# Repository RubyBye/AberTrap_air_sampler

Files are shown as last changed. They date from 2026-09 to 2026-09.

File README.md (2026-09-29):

# AberTrap air sampler

Open-source design for a novel, lightweight, programmable sampler of airborne biological particles. Compatible with eDNA metabarcoding.

This repository contains all the necessary files, instructions, and documentation for constructing and using the AberTrap.  It accompanies [this publication](https://www.biorxiv.org/content/10.64898/2026.09.02.746715v1)

## Device Features

- Portable and lightweight

- Low cost

- Allows for replicated air sampling in hard to reach locations.

- Open-source and programmable for easy modification and development.

## Repository Contents

- Components
    - Details of the components needed for building, programming and deploying your own AberTrap, with example products and suppliers.

- Assembly
    - Documentation on device assembly, including files for 3D printer and laser cutter

- Programming
    - Documentation on programming the microcontroller, including the Arduino sketch files.

- Validation and testing
    - Documentation on how to check that your AberTrap is working as expected

## Getting Started
1. Read the [Publication](https://www.biorxiv.org/content/10.64898/2026.09.02.746715v1)
2. Gather the required materials and equipment as specified in [Components](./Components/).
3. Follow the [Assembly Instructions](./Assembly/AberTrap_Assembly_instructions.md) to build the device.
4. Follow the [Programming Instructions](./Programming/Trinket_programming_instructions.md) to set it spinning.
5. Perform a [Test Run](./Validation_and_testing) to check that it is working as expected.
6. Deploy!

## How to Contribute
We welcome contributions! Please submit a pull request or open an issue if you have suggestions or improvements. For questions or feedback, contact [rub13@aber.ac.uk](mailto:rub13@aber.ac.uk).

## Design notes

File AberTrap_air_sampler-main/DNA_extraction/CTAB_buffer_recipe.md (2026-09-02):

# CTAB buffer recipe

## Ingredients
CTAB DNA extraction buffer contains:
- 100 mM Tris-HCl (pH 8.0)
- 1.4 M NaCl
- 20 mM EDTA
- 2% hexadecyltrimethylammonium bromide (CTAB).

How much to make: Each extraction uses 1ml of CTAB buffer 

## Sterilisation
- sterilise by autoclaving 15 minutes at 121 degrees celsius

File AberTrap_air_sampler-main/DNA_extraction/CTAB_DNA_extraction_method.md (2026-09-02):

# DNA extraction from AberTrap paddles
CTAB method 

## Before starting
Make fresh 70% ethanol. Store in icebox.  

Set heat block to 60 ℃ 

## Method  
- Remove aerosol loaded paddles (stored in 2 ml screwcap microcentrifuge tube) from freezer
   
**In sterile flow cabinet:**

- Add 200 ul of sterile 200 um glass beads to each tube.
- Add 1ml [CTAB buffer](CTAB_buffer_recipe.md). 
- Beat 2 min using Disruptor Genie.
- Transfer tubes to heat block (60 ℃ x 60 min). Vortex 3x during incubation.
- Spin (13,000 rpm x 1 min) to draw down beads. Remove and discard paddles using sterile forceps.
   
**In fume hood:**

- Add 500ul Phenol/chloroform. Vortex until emulsion forms (~ 5 sec). Spin (13,000 rpm x 2 min) to separate phases. 
- Transfer the upper aqueous phase (900 ul, containing the DNA) into a new 2 ml tube.
- Add 500 ul chloroform/isoamyl alcohol (24:1 v/v). Vortex 5 sec. Spin (13,000 rpm x 2 min) to separate phases. 
- Transfer the upper aqueous phase (800 ul, containing the DNA) to a new 1.5 ml tube (this is the final tube so label fully). 
      
**In sterile flow cabinet:** 

- Add 0.7x volume (~560 ul) RT isopropanol to precipitate DNA, with 1.5 ul glycol blue. Vortex briefly. Leave at RT x 5 min. 
- Spin (13,000 rpm x 10 min) to pellet the DNA.
- Pour off the supernatant, taking care to retain the DNA pellet (which will be blue from glyco-blue). 
- Wash:
   - add fresh, cold 70% ethanol (500 ul).
   - Vortex briefly.
   - Pulse spin to re-attach the pellet.
   - Carefully pour off the ethanol, retaining the pellet.
  
- Repeat wash once more.
- Upturn the tube onto a sterile tissue to drain.
- To evaporate residual ethanol, leave with lid open on heat block for 10 min.
- Re-dissolve DNA in [TE buffer](TE_buffer_recipe.md) (100 µl).

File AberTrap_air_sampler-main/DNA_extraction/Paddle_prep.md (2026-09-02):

# Prepare paddles for aerosol capture

## Wash paddles
To remove any grease/contamination aquired during cutting  of perspex sheet

**In sterile PCR cabinet**
1. Detach the paddles from the perspex sheet (making sure to remove both the central pieces from the slots) and drop into a bowl of soapy water
2. Rub gently (with sterile gloves) then rinse in a bowl of sterile water
3. Lay out to dry overnight on paper towels
4. Next day once dry, before greasing, zap with the hood's UV for 15 mins

## Coat with grease
**In sterile flow hood with external extraction**
1. Prepare Vaseline - hexane suspension (50 mg/ml) in a small sterile glass vessel eg 10 ml flask.

*note* Reserve a pot of Vaseline exclusively for this purpose and only open in sterile flow hood.
*note* The hood must be externally venting to safely remove the Hexane fumes during drying. 

2. Mix for approx 15 mins to allow the Vaseline to fully suspend.
3. Using a pair of sterile forceps, dip each paddle into the Vaseline - Hexane suspension. 
4. Place onto a wire rack (still under a sterile flow) to allow evaporation of the Hexane (5 mins), leaving a thin film of Vaseline covering the entire paddle surface.

## Package
1. Fit each greased paddle into the slot on an AberTrap arm. Use a pair of sterile forceps through the donut slots to manipulate.

*note* The curved upper corner of the paddle should face outward of when fitted into the arm. During operation, the direction of AberTrap rotation is clockwise, therefore by fitting the paddle in a known orientation the capture face can be easily determined.

2. Push a 2 ml screwcap centrifuge tube (without lid) over each paddle, where it securely locks into position on the arm. This shroud prevents contamination of the paddle prior to sampling, which is of utmost importance when conducting eDNA analyses.
3. Package the loaded arms into a box ready for transport to the experimental location. Do not remove the shroud from the tube until the arm is fitted to an AberTrap and experiment starts.

*long term storage* if paddles are not to be used immediately, seal into sterile 2ml tube and store double bagged. When needed, fit into arms under sterile conditions as above.

## Control 
To verify that paddles were successfully kept free of contamination, retain both:
- a greased paddle prior to loading onto the arms. Store in one of the sterile 2 ml microcentrifuge tubes used as shrouds.
- a pair of paddles fitted to the AberTrap and covered with shroud. Bring these to the sample site, but return to the lab unopened.

Process these negative controls alongside experimental samples. They should be completely free of DNA.

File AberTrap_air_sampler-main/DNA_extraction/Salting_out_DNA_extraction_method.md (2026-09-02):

# DNA extraction from AberTrap paddles
Salting out method 

## Before starting
Make fresh 70% ethanol. Store in icebox  
Set heat block to 60 ℃ 
Work entirely in PCR cabinet, except for bead beating and incubation steps

## Method  
- Remove aerosol loaded paddles (stored in 2 ml screwcap microcentrifuge tube) from freezer
   
### Macerate tissue
- Add 200 ul of sterile glass disruption beads * to each tube.
- Add salt lysis buffer (515 ul). 
- Beat 5 min using Disruptor Genie.

### Lyse cells
- Add SDS (57 ul = 2% final conc). Vortex briefly to mix. Pulse spin to get everything to bottom of tube
- Transfer tubes to heat block (60 ℃ x 60 min). Vortex every 15 mins incubation.
- Pulse spin (13,000 rpm) to draw down beads. Remove and discard paddles using sterile forceps.
   
### Precipitate proteins
- Add saturated NaCl (400 ul, 0.7x volumes). Vortex. The proteins will precipitate, the DNA remains in solution. 
- Spin down (13,000 rpm x 5 min) to pellet the proteins.
- Transfer supernatant (800 ul, containing the DNA) to a new 1.5ml tube.
- Repeat spindown
- Transfer the supernatant (750 ul) to a new 1.5 ml tube (this is the final tube so label fully)

### Precipitate DNA
- Add room temp isopropanol (~525 ul, 0.7x volumes)  to precipitate DNA, with glycol blue (1.5 ul). Vortex briefly. 
- Leave at room temp x 5 min. 
- Spin (13,000 rpm x 10 min) to pellet the DNA.
- Pour off the supernatant, taking care to retain the DNA pellet (which will be blue from glyco-blue). 

### Wash
- Add fresh, cold 70% ethanol (500 ul). Vortex briefly.
- Pulse spin to re-attach the pellet.
- Carefully pour off the ethanol, retaining the pellet.
- Repeat wash once more. Upturn the tube onto a sterile tissue to drain.
- To evaporate residual ethanol, leave with lid open on 60℃ heat block x 10 min.
- Re-dissolve DNA in [TE buffer](TE_buffer_recipe.md) (100 µl). 

## Buffers & Reagents:
- Salt lysis buffer: Tris 10 mM, NaCl 400 mM, EDTA 2 mM.
- SDS: 20% w/v
- NaCl: 5 M
- Mol grade isopropanol
- [Glyco Blue coprecipitant](https://www.thermofisher.com/order/catalog/product/AM9516) (optional)
- Mol grade ethanol
- [TE buffer](TE_buffer_recipe.md): 1 mM Tris [pH 8.0], 1 mM EDTA

* Glass disruption beads: [RPI Disruption beads 0.5mm for yeast/fungi](https://www.melford.co.uk/products/laboratory-supplies/homogenizers/disruption-beads-for-yeast-fungi-0-5mm-glass-2-5-g-cc-454-gm.html). Measure out a fixed volume of these beads using a 1.5ml tube marked at 200 ul as a measure. Pour the beads into the tube containing the paddle.

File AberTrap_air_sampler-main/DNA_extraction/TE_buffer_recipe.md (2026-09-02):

# TE buffer recipe

## Ingredients

TE DNA storage buffer contains:
- 10 mM Tris (bring to pH 8.0 with HCl)
- 1 mM EDTA

How much to make: Each extraction uses 100 ul of TE buffer

## Method
[This site](https://gatescientific.com/technique-geeks-blog/f/recipes-for-te-tris-edta) has a good walkthrough for how to prepare TE buffer

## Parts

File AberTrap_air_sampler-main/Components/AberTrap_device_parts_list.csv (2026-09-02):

Part | Component | Details | e.g. Brand | e.g. Part num | e.g. Link
Device | Motor | RF-300CA Low inertia DC solar motor, 2 V, rated load 80mA, shaft diameter 2mm. | TruMotion | 37-0441 | https://www.rapidonline.com/trumotion-wrf-300ca-08430-18-5-miniature-low-inertia-solar-motor-2v-1540-rpm-37-0441
Device | Power port | USB C, female, pigtail, waterproof. | AITRIP | B0CKL65V3N | https://www.amazon.co.uk/AITRIP-Chassis-Waterproof-Extension-Connector/dp/B0CKL65V3N
Device | Housing | 50ml centrifuge tube with flat cap, skirted, non-sterile. | Falcon | 3-280-25-8 | https://www.alphalabs.co.uk/3-280-25-8
Device | Sealing tape | Self-Amalgamating rubber tape, black, 3 m x 25 mm. | any | 2115V | https://www.screwfix.com/p/self-amalgamating-rubber-tape-black-3m-x-25mm/2115V
Circuit board assembly | Printed Circuit Board | 22.1 x 34.8 mm PCB ordered from pcbway.com. Gerber filepath: main/Assembly/Assembly_files/Microcontroller/ | pcbway | na | www.pcbway.com
Circuit board assembly | Transistor BC547 | BJT NPN transistor, 100 mA, 45 V, 3 pin TO-92. | onsemi | RS: 761-9828 | https://uk.rs-online.com/web/p/bipolar-transistors/7619828
Circuit board assembly | Transistor BC557 | BJT PNP transistor, -100 mA, -45 V, 3 pin TO-92. | onsemi | RS: 761-3505 | https://uk.rs-online.com/web/p/bipolar-transistors/7613505
Circuit board assembly | PCB Pin headers | 5 pin, 2.54 mm pitch, unshrouded. | Wurth Elektronik | RS:763-6757 | https://uk.rs-online.com/web/p/pcb-headers/7636757
Circuit board assembly | PCB socket | 5 pin, 2.54 mm pitch. Two needed per device. | RS PRO | RS: 251-8200 | https://uk.rs-online.com/web/p/pcb-sockets/2518200
Circuit board assembly | Resistor 470 ohm | 0.25 W, 5% tolerance. | TE Connectivity | RS: 125-1158 | https://uk.rs-online.com/web/p/through-hole-resistors/1251158
Circuit board assembly | Resistor 8k2 ohm | 0.6 W, 1% tolerance (cost a bit more but needed for keeping speed). | TE Connectivity | RS: 148-714 | https://uk.rs-online.com/web/p/through-hole-resistors/0148714
Circuit board assembly | Resistor 1k ohm | 0.6 W, 1% tolerance. | TE Connectivity | RS: 125-1159 | https://uk.rs-online.com/web/p/through-hole-resistors/1251159
Circuit board assembly | Resistor 10k ohm | 0.6 W, 0.5% tolerance. | TE Connectivity | RS: 199-7531 | https://uk.rs-online.com/web/p/through-hole-resistors/1997531
Circuit board assembly | Diode 1N4148 | 400 mA, 100 V, 2 pin DO-35. | Fairchild | RS: 671-5477p | https://uk.rs-online.com/web/p/switching-diodes/6715477P
Circuit board assembly | Microcontroller | Trinket M0. Input 4 to 6 V, output 3.3 V, 500mA. | Adafruit | 1528-2361-ND | https://www.digikey.co.uk/en/products/detail/adafruit-industries-llc/3500/7623049
Power | Power source | 5 V, 20 Ah rechargeable lithium powerbank. USB C out port. Minimum IPX4 | Paidashu |  | https://www.amazon.co.uk/Waterproof-Charger-External-Chargers-Smartphones/dp/B0CKPVNB4F
Power | Power cable | USB C male - USB C male, charge cable, 1m, braided, 40,000+ bend lifespan. | techgear |  | ebay.co.uk/itm/375256246922
Paddles | Acrylic sheet | Paddles laser cut from 1.5 mm acrylic sheet. stl filepath: main/Assembly/Assembly_files/Paddles/ | any | any | retailacrylics.co.uk/2mm-clear-acrylic-sheet-a4-size---297-x-210mm--582-p.asp
Arms | 3D Printer filament | Arms 3D printed from white TPU filament, 1.75 mm, 95a. dxf filepath: main/Assembly/Assembly_files/Arms/ | Polymaker | PD01002 | https://www.123-3d.co.uk/Polymaker-PolyFlex-TPU-90A-filament-1-75-mm-Clear-0-75-kg-PD02004-i9925-t104858.html

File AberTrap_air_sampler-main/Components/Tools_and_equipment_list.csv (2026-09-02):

Item | Details | e.g. Brand | e.g. Part num | e.g. Link
Soldering iron | Soldering station | RS PRO | RS: 202-4512 | https://uk.rs-online.com/web/p/soldering-stations/2024512
Soldering iron tips | 0.8 mm Straight Conical Soldering Iron Tip | RS PRO | RS: 799-8985 | https://uk.rs-online.com/web/p/soldering-iron-tips/7998985
3D printer | Printbed size: fits at least 1 AberTrap Arm (10cm wide) | Robox (discontinued) | RBX01-BK | https://www.idig3dprinting.co.uk/shop/brand/cel-uk/robox-3d-printer/
Tacometer | Tachometer Best Accuracy ±0.05 % | RS PRO | RS:193-8687 | https://uk.rs-online.com/web/p/tachometers/1938687
Solder wire | 0.8mm Lead Free Solder, 227°C Melting Point. Use lead free, needs slightly higher temp | RS PRO | RS: 818-3204 | https://uk.rs-online.com/web/p/solder/8183204
Glue gun + glue sticks | none | any | any
Stainless steel core borer | Diameter: 7mm | any | any
Stainless steel needle | Diameter: 2mm | any | any
Laser cutter | Suitable for A4 2mm Acrylic | any | any
Drill and bit | For making holes in wooden poles for retort stand arms | any | any
Solder 3rd hand | Device for holding components stable while soldering | any | any

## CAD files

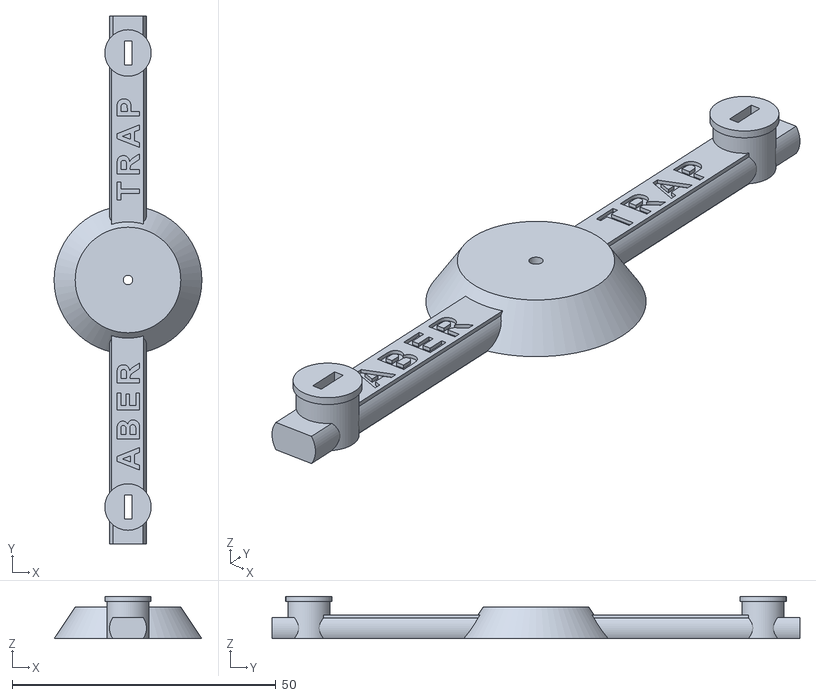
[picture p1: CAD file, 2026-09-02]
AberTrap_air_sampler-main/Assembly/Assembly_files/Arms/AberTrapArm.stl
28.0 x 100.0 x 8.00

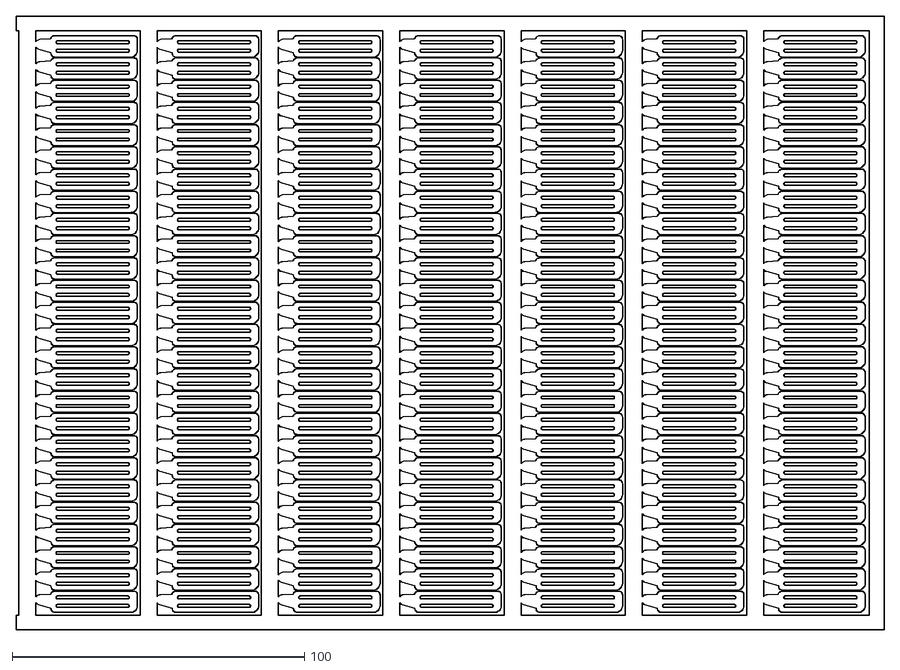
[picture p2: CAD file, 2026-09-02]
AberTrap_air_sampler-main/Assembly/Assembly_files/Paddles/Paddles_00_A4-Sept24.dxf
297.0 x 210.0

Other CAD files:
AberTrap_air_sampler-main/Assembly/Assembly_files/Battery_enclosure/abertrap_housing_upper_cap.stl
AberTrap_air_sampler-main/Assembly/Assembly_files/Battery_enclosure/abertrap_housing_lower_cap.stl

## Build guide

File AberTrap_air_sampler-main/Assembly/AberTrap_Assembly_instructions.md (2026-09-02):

This page provides instructions on AberTrap assembly.

# 1. **Housing**

- Adapt the 50ml centrifuge tube to accommodate the AberTrap's wiring:
  - Make a hole in the tube lid for the motor cable, using either a hot 2 mm stainless steel needle, or drill. Make sure that the hole is inset enough that the motor leads will not be pinched in the screwthread when the lid is put back on.
  - Make an approx 15 mm oblong hole at the base of the tube for the power port to sit in (Figure s1), using either a hot 7 mm diameter core borer, or 7 mm drill bit.

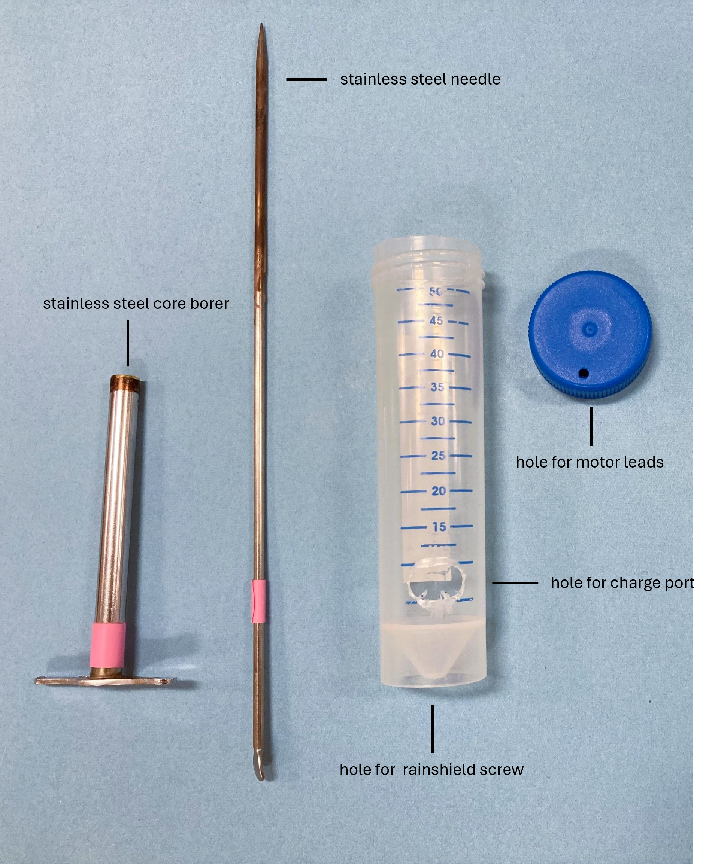
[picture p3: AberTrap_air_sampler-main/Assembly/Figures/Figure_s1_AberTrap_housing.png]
Figure s1


*Figure s1 Modifying the AberTrap housing (50ml falcon) to accommodate wiring*

# 2. **Circuitry**

Assemble the AberTrap components as per the circuit diagram (Figure s2), in the following order:

1. **Circuit board assembly**. Use the layout printed on the PCB (Figure s3) to populate the PCB with [the components](AberTrap_device_parts_list.csv). Solder components into place on the underside of the board. Its easiest to add a few components first, solder these, clip off the spare [legs] then add a few more.
   *note* Ensure the correct orientation of the diode [part num] and transistors [part num], as indicted on the PCB.

    - **Microcontroller.** Solder pin headers onto the Trinket. When mounting the Trinket onto the pin sockets (soldered onto the PCB), ensure the correct orientation of pins; the text “Trinket M0” should be oriented towards the battery connection points, with the microUSB aligning with the mouth of the centrifuge tube (Figure s3B). See [this page](https://learn.adafruit.com/adafruit-trinket-m0-circuitpython-arduino/pinouts) for explanation of the Trinket pins.

3. **Motor.** Insert the motor leads through the newly made hole in the lid of the centrifuge tube. Secure the motor to the lid by first affixing into a small blob of hot glue, into which the motor is pressed. Then secure the motor in place by wrapping the motor and lid with self-amalgamating tape (Figure s4). Solder the motor leads onto to the PCB as indicated at the “M+” (red lead) and “M-“ (black lead) connection points. 

4. **Power.** Inset the USBC power port into the newly made hole in the body of the centrifuge tube (Figure s1). Connect the leads of the port to the PCB as indicated at the “B+” (red lead) and “B-" (black lead) connection points (Figure s3A). Add a blob of hot glue to both the motor and power connection points for extra strength

5. Push the finished circuit board assembly into the adapted centrifuge tube. A twisting motion helps coil the leads to the bottom of the tube, allowing the PCB to fit. Screw on the lid, making sure that the motor leads are not pinched in the screwthread. 

The assembled AberTrap (Figure s4) is now ready for programming.

---

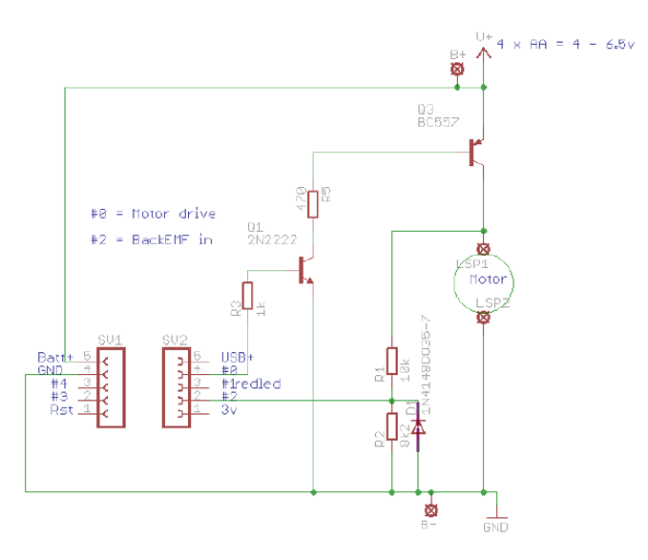
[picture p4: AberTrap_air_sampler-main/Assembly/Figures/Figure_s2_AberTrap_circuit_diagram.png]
Figure s2


*Figure s2 AberTrap circuit diagram*

---

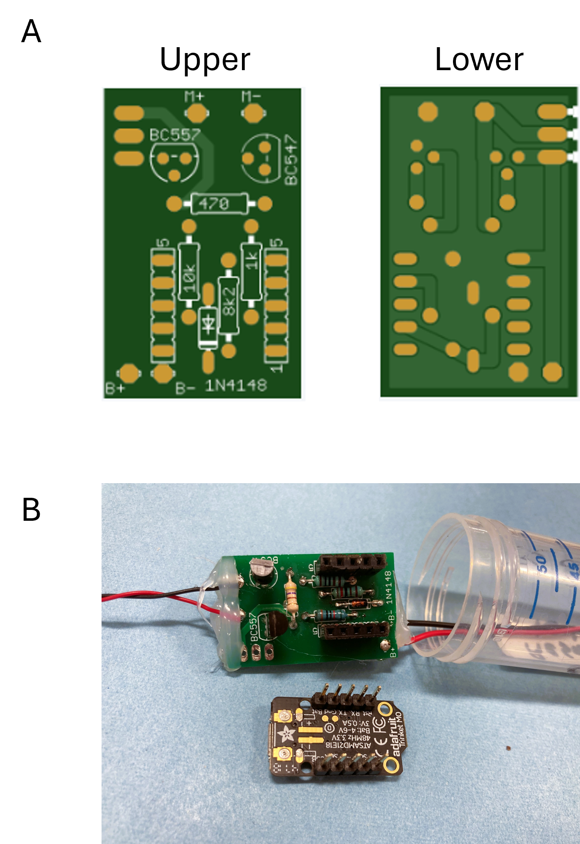
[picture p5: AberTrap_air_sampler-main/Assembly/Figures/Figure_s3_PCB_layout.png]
Figure s3


*Figure s3 A) Layout of the PCB showing positioning of each of the circuit components B) Photograph of a complete circuit board assembly, including Trinket microcontroller, power and motor leads*

---

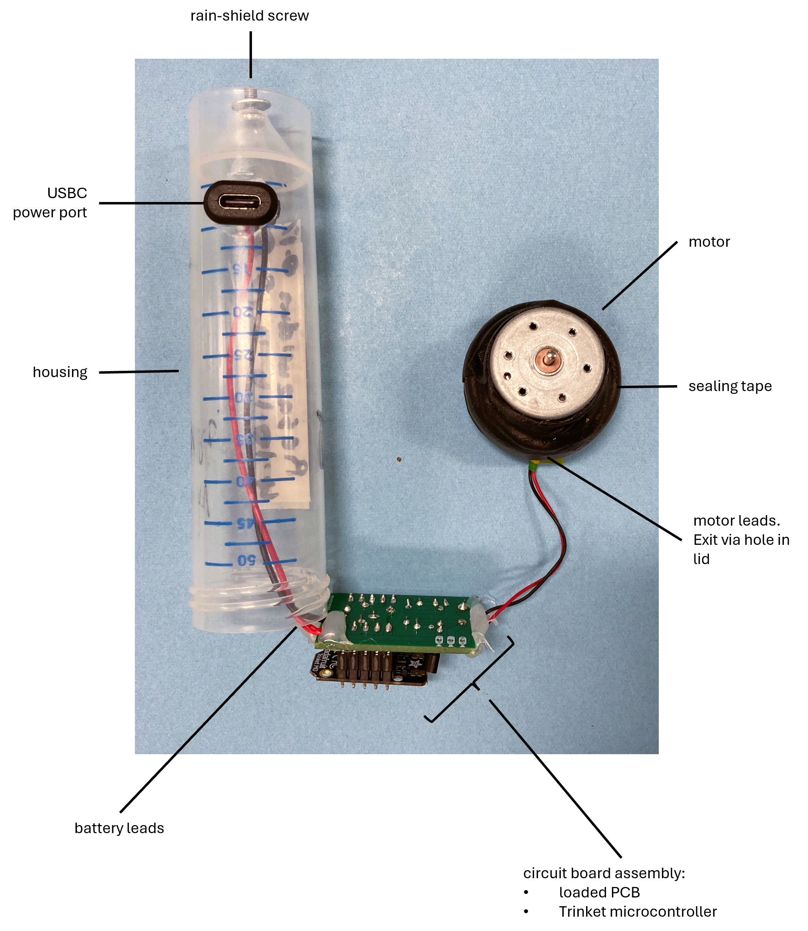
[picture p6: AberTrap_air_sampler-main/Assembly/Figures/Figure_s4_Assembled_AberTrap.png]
Figure s4


*Figure s4 labelled photograph of an assembled AberTrap*

---

# 3. **Arms**
Rotating arms are printed from 0.75mm TPU (95a shore hardness). Print files are available in the [Assembly_files](Assembly_files). Each arm can be reused several times; for metabarcoding we recommend washing and sterilising arms between each use. 

# 4. **Battery Enclosure**
When deployed outdoors such as woodland or grassland, the AberTraps should be mounted at a fixed height from the ground. This can be achieved by sticking a wooden pole in the ground. eg Broom handle. Height= 1500 mm, diameter= 28 mm. 

The AberTrap can be mounted onto this pole in a waterproof enclosure holding the battery and cabling. This enclosure is made from 100mm (internal diameter) plastic pipe, cut into lengths. Files for 3D printing flexible upper and lower end caps from 95a TPU are provided in the [Assembly_files](Assembly_files). The lower cap has an offset hole through which the AberTrap can be pushed, allowing the USBC port and battery to be hidden from rain. Use velcro strapping to attach the enclosure to the pole.    

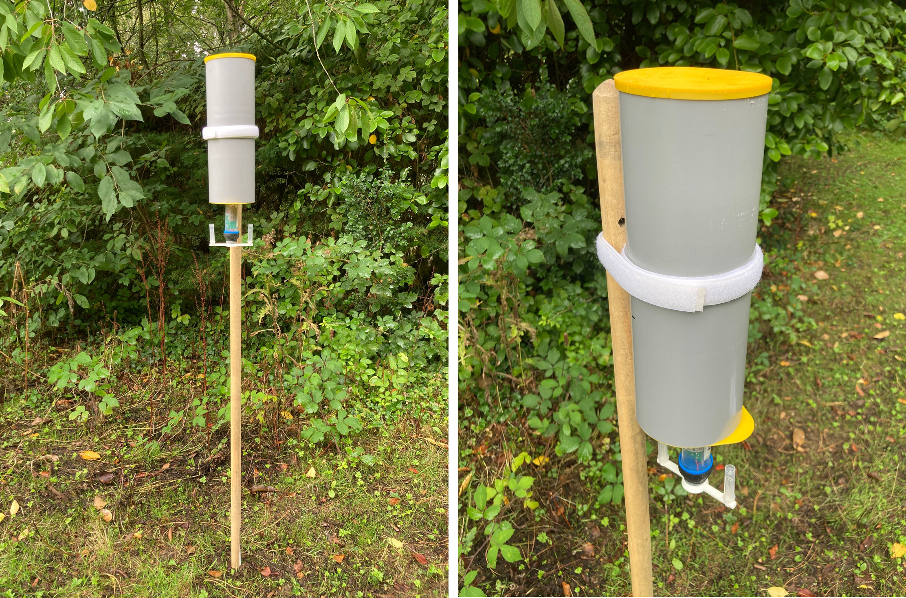
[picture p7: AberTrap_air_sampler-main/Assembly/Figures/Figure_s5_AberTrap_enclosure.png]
Figure s5


*Figure s5 Battery enclosure for outdoor operation*

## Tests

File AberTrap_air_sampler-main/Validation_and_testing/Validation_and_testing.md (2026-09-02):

# Test Run
Perform these basic checks before deploying the samplers in the field:

## **Check RPM with taco**
* Affix reflective strip to the underside of an AberTrap arm. 
* Secure a programmed AberTrap eg in a retort stand, with the Tacometer mounted below. Both devices must be completely stationary during tesing, otherwise erroneous readings will be obtained. 
* Connect AberTrap to power supply
* Record rotational speed (rpm) after 30seconds rotation. Divide this value by 2 to get the actual rpm. 

## **Draindown to check battery duration**
* Fully charge power supply. 
* Mount programed AberTrap, complete with paddles, in a retort stand. Connect to the power supply
* Record date and time of rotation start and stop. This is your runtime.  

# Troubleshooting

## **Trinket M0 package not available**

When just downloading a fresh version of the Arduino IDE, the package for the Trinket M0 isn't included so this needs to be installed for recognition by the software. 

- File > Preferences > Additional Boards Manager URLs: > Paste in this link: https://adafruit.github.io/arduino-board-index/package_adafruit_index.json
- Tools > Board > Board Manager > Install: Adafruit SAMD Board
- Select Adafruit Trinket M0 board
- Set up a new folder eg named AberTrap_prog and place all .ino files in this folder. Then New sketch > File Open > AberTrap_prog.ino
- Double click button then go to Tools > Port > Select correct USB port for Trinket (I have found when unplugging and plugging a new one in sometimes it wants to change the port number, so this is my solution)
- Then press the button once and click upload

## **Trinket bootloader update**
If you get this Error message:

"Sketch uses 19100 bytes (7%) of program storage space. Maximum is 262144 bytes. Device unsupported Failed uploading: uploading error: exit status 1"

Then for some reason the .uf2 file might be outdated on your trinket, which causes issues with the device being recognized. 

Fix this by:
 1. Download [an updated bootloader](https://github.com/adafruit/uf2-samdx1/releases/download/v3.16.0/update-bootloader-trinket_m0-v3.16.0.uf2) from the adafruit/uf2-samdx1 github page 
 2. Double clicking the trinket button to open the bootloader (window that pops up under the drive TRINKETBOOT).
 3. Upload the updated bootloader. If it loads correctly, it should close the window.
 4. Then press the trinket button once and sketch upload should work.

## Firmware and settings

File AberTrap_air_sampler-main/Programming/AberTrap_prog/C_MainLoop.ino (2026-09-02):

// INITIALISATION
void setup() {                        	                    // The setup routine runs once when you press reset or apply power
  delay(DelayMinutes * 60000);                              // Pause the sketch for the desired time (in minutes) before the air sampler starts
  analogReference(AR_INTERNAL1V0);                          // Analogue to Digital Converter 10 bit (0 - 1024). 1.0v reference for the M0 (instead of 1.1V for the V3 board)
  
// PIN SETUP.
 
  pinMode(MOTOR, OUTPUT);                                   // Sets the motor pin as output
  pinMode (LED, OUTPUT);                                    // Sets the LED pin as output
  pinMode(BackEMF, INPUT);                                  // Sets the backEMF pin as input
  digitalWrite(MOTOR,OFF);                                  // Ensures the motor is initially off
  
// SET SPEED CORRECTION SETUP.  
// set speed correction factor. we are measuring back-EMF not speed directly and there is some non-linearity.
  if (FASTrpm < 1500)
    {
      correction = 3.4;
    }
  else
    {
      correction = 2.0;
    }  
  SpeedRef = FASTrpm / correction;                          // Set the reference speed after applying the correction factor

//SET MOTOR PULSE WIDTH, depending on desired RPM.

  if (FASTrpm < 400)                                        // Increase the pulse width at low speeds
    {
      Pulse_Width = FASTrpm * 1.2;
    }
   else
   {
      Pulse_Width = FASTrpm * 4;                            // At higher speeds, increase the pulse width to 5 times the user-defined rpm
   }  
 }

//MAIN LOOP EXECUTION. The loop routine runs over and over again forever
void loop() {
  // CHECK IF OPERATION IS ONGOING

  	if (End == false)
   		{                                                     // Checks if it is still within the designated run time, if so (End=false), moves on to the rest of the loop.
    		Timer();                                            // Runs the 'Timer' subroutine to track total run time.
		    IntTimer();                                         // Runs the 'IntTimer' subroutine to track time spent in the current FAST/SLOW interval

        // CYCLE TIME COUNTING
    		if(seconds != seconds_last)
      			cycletimesecs++;                                // Increase cycle counter every time a second passes
    		seconds_last = seconds;                             // Update last recorded second
    		if(cycletimesecs == 600)                            // Reset cycle counter after 600 seconds (10 mins)
             		cycletimesecs = 0;
        	
          // MOTOR CONTROL
          if (Run == true)                                  // If the motor is running...
          		{	
    		  	if(cycletimesecs < CycleSeconds)                //...and cycle time is still within the specified CycleSeconds
    			  	{
         		  	Speed();                                    // Calls the 'Speed' subroutine to set the desired pwm (power to the motor) to maintain RPM
    			  	} 
    		  	else
    			  	{
         		  	digitalWrite (MOTOR,0);                     // Otherwise, if cycle time exceeded, turns off motor
    			  	} 
          		}
 		  }
  // CHECK IF THE TOTAL RUNTIME LIMIT HAS BEEN REACHED 
 	if (minutes >= RunMinutes)
   		{                                                     // Checks to see if we have reached the user-defined runtime.
     		if (hours >= RunHours)
     			{
      			End = true;                                     // If so, changes the value of 'End' to True to stop the main loop completing next time. End the loop after reaching desired runtime
      			digitalWrite (MOTOR,0);                         // Turns off the motor
     			}
  		}

//FAST/SLOW INTERVAL SWITCHING
	if (SlowInterval == false)                                // If currently in a 'FAST interval'
		{
		if (Intminutes >= FASTmin)				                      // checks if user-defined 'FAST interval' duration has been reached 
			{
			SlowInterval = true;                                  // If yes, switch to the 'SLOW interval'
			Intseconds = 0;
			Intminutes = 0;
      digitalWrite (MOTOR,0);                               // Slow or pause the motor
			PrevSpeed = SpeedRef;                                 // Stores the previous speed reference
			SpeedRef = SLOWrpm;                                   // Set motor speed to the user-defined 'SLOW interval' speed (in rpm) 
			}
		}
	else                                                      // If currently in a 'SLOW interval'
		{
		if (Intminutes >= SLOWmin)			                       	// Checks if user-defined 'SLOW interval' duration has been reached  
			{
			SlowInterval = false;                                 // If so, switch back to 'FAST interval' 
			Run = true;
			SpeedRef = PrevSpeed;                                 // Restore the previous 'FAST interval' speed ; re-starts spinning at full speed
			Intseconds = 0;                                       // Resets the interval counter 
			Intminutes = 0;
			}
		}
   	}

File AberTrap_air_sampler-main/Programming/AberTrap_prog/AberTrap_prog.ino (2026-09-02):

// USER INPUT. modify values of the parameters below to set the AberTrap run program
/*
Speed range 200 - 1600 RPM


*/
int RunMinutes = 0;                      // USER INPUT. Sets the desired total runtime in minutes (0 - 59). This determines how long the program will run (in minutes). set to 0 if timing in hours
int RunHours = 730;                      // USER INPUT. Sets the desired total runtime in hours (no max value). This determines how long the program will run (in hours)
int DelayMinutes = 0;                    // USER INPUT. Sets the desired time delay (in minutes) before rotation starts.
int CycleSeconds = 600;                  // USER INPUT. Sets the number of seconds in a 600-second cycle that the motor will be running. For example, if CycleSeconds = 300, the motor would run for 300s and stay off for the remaining 300s of the cycle

//set duration and rpm for the "FAST/SLOW" intervals. The sampler will keep cycling between these intervals until the total Run time is reached
int FASTrpm = 1600;                 	   // USER INPUT. Sets the desired motor speed (in revolutions per minute; rpm) for FAST speed intervals 
int FASTmin = 1;                         // USER INPUT. Sets the duration (in minutes) of FAST speed intervals. 
int SLOWrpm = 10;                        // USER INPUT. Sets the motor speed for SLOW speed intervals. Meant to be in RPM but not, "10" seems to be approx 400rpm needs work to slow it down. Set to "0" for a complete PAUSE.
int SLOWmin = 1;                         // USER INPUT. Sets the duration (in minutes) of SLOW speed intervals. Set to "0" for continuous FAST.
